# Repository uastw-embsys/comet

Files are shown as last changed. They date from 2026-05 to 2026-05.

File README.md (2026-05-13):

<!-- SPDX-License-Identifier: CC-BY-SA-4.0 -->

# COMET - Cost-efficient Open-Source Multicopter for Embedded-Systems Teaching

<div align="center">
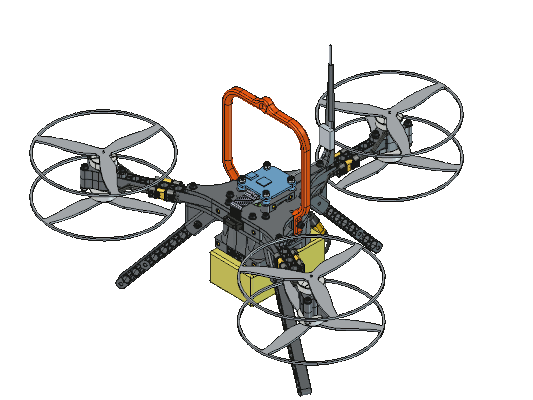
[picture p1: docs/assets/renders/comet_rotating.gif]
    
</div>

<!-- https://github.com/badges/shields -->
<!-- ![GitHub Release](https://img.shields.io/github/v/release/uastw-embsys/comet?display_name=tag)  -->
 

## Description

COMET is an open-source, cost-efficient Y6 hexacopter platform designed for education and research in embedded and cyber-physical systems. It features a fully 3D-printed, modular Y-frame with coaxial brushless DC motors and propellers that provide redundancy in propulsion. COMET also has a standardized motor-controller connector that allows for the easy integration of your preferred flight controller. This repository includes CAD sources, printable STL files, 3MF slicer projects, a bill of materials, a comprehensive build manual, and a ready-to-fly INAV configuration to ensure easy reproducibility.

Key specifications:
- Build it for less than $600 in total
- Frame size: 30cm
- Propellers: 5.1x2.5 (3 blades)
- Motors: 2004 1600KV-1900KV
- Power: 6S LiPo
- Recommended 3D printing materials: PC/CF for the frame and PETG for color coding.
- The recommended electronics are listed in the [bill of materials](/docs/bill_of_materials.ods).

## Table of Contents

- [Documentation](#documentation)
- [Repository Structure](#repository-structure)
- [Safety](#safety)
- [Releases and Versioning](#releases-and-versioning)
- [Licenses](#licenses)
- [Cite This Work](#cite-this-work)
- [OSHWA Certification (planned)](#oshwa-certification-planned)
- [Authors and Acknowledgment](#authors-and-acknowledgment)
- [Disclaimer](#disclaimer)

## Documentation

- Access the project website and documentation through: https://uastw-embsys.github.io/comet
- Latest release: https://github.com/uastw-embsys/comet/releases

Quick links:
  - Bill of Materials: [docs/bill_of_materials.ods](/docs/bill_of_materials.ods)
  - Printing guide: [docs/printing.md](/docs/printing.md)
  - Build manual: [docs/build.md](/docs/build.md)
  - FCU and ESC config: [docs/config.md](/docs/config.md)
  - Safety instructions: [docs/safety.md](/docs/safety.md)

[Back to the top &#8593;](#comet---cost-efficient-open-source-multicopter-for-embedded-systems-teaching)

## Repository Structure

In this repository, "mechanical" refers to printed parts, mechanical components, and assemblies, while "electronics" refers to commercial off-the-shelf (COTS) drone components, wiring, and configurations. According to the OSHWA definition, both are part of the “hardware”, but we separate them for clarity.

### Folders and Files

```
/
├── LICENSES/                            # Contains all licenses that are used
├── docs/
│   ├── assets/
│   │   ├── fonts/                       # Fonts used in the project
│   │   ├── images/                      # Pictures used in all Markdown files
│   │   └── renders/                     # Exported screenshots and animations
│   ├── assembly.md
│   ├── bill_of_materials.ods            # Detailed list of all parts needed
│   ├── build.md                         # Instructions for building COMET hardware
│   ├── config.md                        # Instructions for configuring COMET electronics
│   ├── index.md                         # Documentation landing page
│   ├── printing.md                      # Instructions for printing COMET hardware
│   └── safety.md                        # General drone/COMET safety instructions
├── electronics/
│   ├── esc/                             # Supported ESC configs (e.g., Bluejay)
│   │   └── bluejay/
│   │       └── configs/
│   │           └── <VERSION>/
│   │               ├── <TARGET>/        # YAML file documents all parameter values
│   │               │   ├── esc-configurator-*.png
│   │               │   └── parameters-*.yaml
│   │               └── README.md        # Description of how to configure ESCs
│   ├── fcu/                             # Supported FCU configs (e.g., INAV)
│   │   └── inav/
│   │       └── configs/
│   │           └── <VERSION>/
│   │               ├── <TARGET>/
│   │               │   └── diff-*.txt   # Contains all setting changes
│   │               └── README.md        # Description of how to configure the FCU
│   └── wiring/
│       └── wiring-diagram.svg           # Shows how components are connected and interfaced
├── mechanical/
│   ├── exports/                         # Generated artifacts (STEP and STL, do not edit)
│   ├── prints/                          # Supported slicer configs (e.g., PrusaSlicer)
│   │   ├── prusaslicer/
│   │   │   └── <PRINTER>/               # Printer-specific (e.g., COREONE) project files
│   │   │       └── <MATERIAL>/          # At least one folder named after the material(s) used
│   │   │       │   ├── clearance-gauge-*.3mf
│   │   │       │   ├── color-coding-*.3mf
│   │   │       │   └── frame-*.3mf
│   │   │       └── prusaslicer-bundle-Prusa<PRINTER>.ini
│   │   └── README.md
│   └── source/
│       ├── assemblies/                  # FreeCAD assemblies (A2plus workbench)
│       ├── calibration/
│       │   ├── clearance_gauge.FCStd
│       │   └── README.md
│       ├── macros/
│       │   ├── apply_parameters.py      # Apply part settings to FreeCAD parts
│       │   ├── common_fc.py
│       │   └── export_source.py         # FreeCAD export script
│       ├── part_parameters.yaml         # FreeCAD YAML parameter file
│       ├── parts/                       # FreeCAD part files (one Body per part)
│       └── README.md
└── README.md
```

### Source vs. Exports
The "source" (preferred form for modification) is under `mechanical/source/`. Generated artifacts (STL/STEP and 3MF) are under `mechanical/exports/` and `mechanical/prints/` after the use of `scripts/export_source.py`.

[Back to the top &#8593;](#comet---cost-efficient-open-source-multicopter-for-embedded-systems-teaching)

## Safety

Drones combine fast-spinning parts, high-energy batteries, and radio-controlled systems. Take a few simple precautions to reduce the risk of injury, equipment damage, and legal complications.

Treat setup and testing as seriously as flight:
- Remove propellers during INAV or Bluejay configuration and bench testing.
- Verify the motor spin direction and failsafes before putting propellers on.
- Follow local UAV regulations and only fly in permitted, safe areas within your line of sight.
- Handle LiPo batteries carefully and follow the best practices for charging and storing them.

Detailed **safety instructions** can be found in the [`docs/safety.md`](/docs/safety.md) file.

[Back to the top &#8593;](#comet---cost-efficient-open-source-multicopter-for-embedded-systems-teaching)

## Releases and Versioning

All releases use a semantic versioning scheme: MAJOR.MINOR.PATCH (e.g., v1.0.0).

Each release includes:
  - STEP and STL files for all printed parts
  - 3MF and INI project files for different 3D printers
  - PDF of the bill of materials
  - PDF of the documentation (e.g., build manual)
  - INAV and Bluejay configuration files

[Back to the top &#8593;](#comet---cost-efficient-open-source-multicopter-for-embedded-systems-teaching)

## Licenses

License application by content type:

- Hardware (e.g., CAD sources):  
CERN-OHL-W v2 - see [`LICENSES/LICENSE.CERN-OHL-W-2.0.txt`](/LICENSES/LICENSE.CERN-OHL-W-2.0.txt).
- Documentation (e.g., manuals or photos):  
CC BY-SA 4.0 - see [`LICENSES/LICENSE.CC-BY-SA-4.0.txt`](/LICENSES/LICENSE.CC-BY-SA-4.0.txt).
- Configuration Files (e.g., INAV or Bluejay):  
CC0-1.0 - see [`LICENSES/LICENSE.CC0-1.0.txt`](/LICENSES/LICENSE.CC0-1.0.txt).
- Software (e.g., scripts):  
LGPLv3 - see [`LICENSES/LICENSE.LGPL-3.0.txt`](/LICENSES/LICENSE.LGPL-3.0.txt).
- This project uses the Teko font, designed by Indian Type Foundry (2014), available under the SIL Open Font License, Version 1.1 - see [`docs/assets/fonts/teko/OFL.txt`](/docs/assets/fonts/teko/OFL.txt).

By contributing, you agree that your contributions are provided under the same licenses.

[Back to the top &#8593;](#comet---cost-efficient-open-source-multicopter-for-embedded-systems-teaching)

## Cite This Work

If you use or adapt the device for any academic or industrial purpose, especially if you publish it, please cite this repository and the relevant prior work.

### BibTeX repository
```bibtex
@misc{Comet_v1_0_0,
  author = {Christoph Böhm and Roman Beneder},
  title = {GitHub Repository: COMET - Cost-Efficient Open-Source Multicopter for Embedded Systems Teaching},
  year = {2026},
  howpublished = {\url{https://github.com/uastw-embsys/comet}},
  note = {DOI pending; version 1.0.0}
}
```

### BibTeX companion paper
```bibtex
@article{CometPaper2026,
  author  = {Christoph Böhm and Roman Beneder},
  title   = {COMET: Cost-Efficient Open-Source Multicopter for Embedded Systems Teaching},
  journal = {TechRxiv},
  volume = {2026},
  number = {0227},
  pages = {},
  year = {2026},
  doi = {10.36227/techrxiv.177222563.34103951/v1}
}
```

<!-- Once Zenodo is enabled and a release is archived, replace the “pending” text and add the Zenodo badge -->

[Back to the top &#8593;](#comet---cost-efficient-open-source-multicopter-for-embedded-systems-teaching)

## OSHWA Certification (planned)

- OSHWA UID: **Certification pending**; The planned certification UID (e.g., US000XXX) will be added here once approved. We plan to certify under OSHWA once v1.0.0 is released and the documentation is finished.
- This project complies with the Open Source Hardware Definition: https://www.oshwa.org/definition/
- Certification details and logo usage: https://certification.oshwa.org/

Interim Compliance Summary:

- Editable design files (FreeCAD .FCStd)
- Manufacturing files (STEP/STL)
- 3D print project files (3MF/INI)
- Bill of materials including standards and suppliers
- Build and configuration instructions (multiple manuals)
- Open licenses applied and documented

[Back to the top &#8593;](#comet---cost-efficient-open-source-multicopter-for-embedded-systems-teaching)

## Authors and Acknowledgment

### Authors (Credit roles in parentheses)

- [Christoph Böhm](https://scholar.google.com/citations?user=uV0KBoEAAAAJ) (Project initiator, developer, and maintainer)
- [Roman Beneder](https://embsys.technikum-wien.at/staff/beneder/index.php) (Project co-developer and test pilot)

Corresponding author: **Christoph Böhm** - christoph.boehm@ieee.org

### Contributors

- [Johannes Anderle](https://embsys.technikum-wien.at/staff/anderle/index.php)
- [Samuel Bauer](https://embsys.technikum-wien.at/staff/bauer/index.php)
- [Christian Fibich](https://embsys.technikum-wien.at/staff/fibich/index.php)
- [Ilva Heindl](https://embsys.technikum-wien.at/staff/heindl/index.php)
- [Ana Kokic](https://embsys.technikum-wien.at/staff/kokic/index.php)
- [Patrick Schmitt](https://embsys.technikum-wien.at/staff/schmitt/index.php)

### Acknowledgments

- [Research Group: Embedded Systems](https://embsys.technikum-wien.at/) for funding, workspace, and equipment
- We thank the open‑source communities whose software and content we rely on, including but not limited to:
  - FreeCAD and community workbenches
  - INAV flight software and INAV Configurator
  - Slicers used for supplied profiles (e.g., PrusaSlicer)
  - Icons and fonts used in this project
<!-- - This work was partially supported by <Grant/Company> (Grant no. XXX) -->

[Back to the top &#8593;](#comet---cost-efficient-open-source-multicopter-for-embedded-systems-teaching)

## Disclaimer
**This is experimental hardware. Use it at your own risk and comply with all local laws and regulations.**

[Back to the top &#8593;](#comet---cost-efficient-open-source-multicopter-for-embedded-systems-teaching)

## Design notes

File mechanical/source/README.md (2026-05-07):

<!-- SPDX-License-Identifier: CC-BY-SA-4.0 -->
# Source README

This directory contains the “Source” for the hardware design — the preferred form for making modifications — as required by the CERN Open Hardware License v2 (CERN‑OHL‑W).

What this means
- The FreeCAD `*.FCStd` files here are editable project sources.
- Generated artifacts (STL/STEP/3MF) live under `../exports/` and are not the canonical editing form.
- If you redistribute Products based on this design, you must provide a notice pointing to this Source and license.

## Contents and conventions

- parts/
  - One manufacturable part per `*.FCStd`
  - Each file has a top‑level Body with a stable Label (e.g., `mounting_plate`, `rotor_arm`)
  - Parameters stored in a Spreadsheet object (Label: `params`), referenced by aliases (e.g., `'m3_hole_diameter_clearance`, `'threaded_insert_outer_diameter`)
- assemblies/
  - Assembly files (e.g., Assembly3) linking parts via `App::Link`
  - Local Coordinate Systems (LCS) used for constraints
- params/
  - YAML parameter sets (e.g., `default.yaml`, variant files)

FreeCAD version
- Designed and tested with 1.1.0.44227 +568 (Git) Snap 2266. Other versions may work but are not guaranteed.

## Editing guidelines

- Avoid attaching sketches/features to generated faces (topological naming issue). Use Datum planes/axes and LCS.
- Keep a “master sketch” per part for core layout; parameterize via the `params` Spreadsheet.
- Apply fillets/chamfers late in the feature tree.
- Name key features (e.g., `Sketch_Master`, `Pad_Main`, `Hole_M3_Insert`) for clarity.
- Update revision numbers (R#) in file names and meta when geometry changes.

## Parameters and variants

- Default parameters are stored in each part’s `params` Spreadsheet.
- Variant sets live under `params/variants/`. Load them before recompute/export (see scripts).
- Typical aliases:
  - `m3_hole_diameter_clearance`, `threaded_insert_outer_diameter`, etc.

## Assemblies

- Use stable Labels in parts so assembly links don’t break.
- Constrain via LCS‑to‑LCS where possible.
- Keep sub‑assemblies (e.g., `motor_block`) separate and link into the main assembly.

## Exporting

- Exports are generated headless via `freecad.cmd` using `scripts/export_freecad.py`.
- STL/STEP/3MF are written to `../exports/`.
- Do not hand‑edit exports; modify the `*.FCStd` source and re‑export.

## Licensing

- SPDX for source files: `CERN-OHL-W-2.0`
- Include license and source URL in FreeCAD document metadata:
  - Document → Properties → Meta → `License = CERN-OHL-W-2.0`
  - `Comment = Source: https://github.com/uastw-embsys/comet`
- Full license text: `LICENSES/LICENSE.CERN-OHL-W-2.0.txt`

Third‑party models

- External CAD (e.g., GrabCAD) must be segregated under `third-party/` with clear attribution and original license. These files are not covered by CERN‑OHL‑W unless explicitly stated.
- See `LICENSES/THIRD-PARTY-NOTICES.md` for details.

## Contributing

- Edit `*.FCStd` in `parts/` or `assemblies/` only; keep exports in sync via scripts.
- Add/maintain parameter aliases for new features.
- Run validation scripts (dimension/mesh checks) before submitting PRs.
- Use SPDX headers in text files and keep meta info updated in `*.FCStd`.

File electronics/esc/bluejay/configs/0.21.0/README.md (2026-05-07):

<!-- SPDX-License-Identifier: CC-BY-SA-4.0 -->

# Bluejay 0.21.0 Configurations

This folder contains configuration files for supported electronic speed controller targets tested with COMET using Bluejay. Use the ESC Configurator to flash your electronic speed controller(s) with the official Bluejay 0.21.0 release, then apply the appropriate settings.

- Bluejay 0.21.0 release: https://github.com/bird-sanctuary/bluejay/releases/tag/v0.21.0
- ESC Configurator: https://esc-configurator.com/

Note: These configurations are intended for BLHeli_S electronic speed controllers that are compatible with Bluejay (no support for BLHeli_32).

## Supported targets

- [J-H-50 (4-in-1)](https://www.speedybee.com/speedybee-f405-bls-50a-30x30-4-in-1-esc/): [configs/0.21.0/J-H-50/parameters-bluejay-0.21.0-J-H-50.yaml](/J-H-50/parameters-bluejay-0.21.0-J-H-50.yaml)
- [Q-H-50 (4-in-1)](https://www.rotorama.com/product/skystars-ko50a-bls): [configs/0.21.0/Q-H-50/parameters-bluejay-0.21.0-Q-H-50.yaml](/Q-H-50/parameters-bluejay-0.21.0-Q-H-50.yaml)

If your build uses a different target, create a new subfolder under `0.21.0/` using the Bluejay target name, as shown in the ESC Configurator.

## Prerequisites

- ESC Configurator reachable and up to date
- **Propellers removed** and LiPo connected and powering the ESC(s)
- Stable USB connection through FCU pass-through

## Apply the configuration

Steps to follow:
1) Open https://esc-configurator.com/ in a Chromium-based browser.
2) Connect to the ESC(s) and click "Read Settings" to ensure a stable USB connection and pass-through.
3) Click on "Flash All ESCs" and select the following settings:
   - Firmware: Bluejay
   - ESC (Target): Select the exact target (e.g., Q-H-30). If you are unsure, use Auto-Detect, then confirm against the ESC silkscreen or datasheet.
   - Version: 0.21.0
   - PWM Frequency: Select the value defined by the `pwm_khz` variable in the chosen target parameters file: `parameters-bluejay-0.21.0-<TARGET>.txt`.
4) Wait until all the ESCs have been flashed.
5) Update the values of the parameters in the "Common Parameters" section to match the values specified in the file `parameters-bluejay-0.21.0-<TARGET>.txt.`
6) Click "Write Settings" and, if prompted, power-cycle the ESC.

A note about the motor spin direction: You can adjust the motor direction through the motor ESC wiring, the Bluejay configuration, or the INAV configuration. **The first option is preferred for consistency.**

## Post-flash checks

After applying the new settings:
- Verify motor order and direction. Use the INAV Configurators Output tab to spin individual motors.
- Perform a short throttle range test without the propellers to confirm that there is no desyncing (stuttering or stopping) or excessive heat.

## Troubleshooting

- ESC not detected: Provide external power or follow the bootloader pad procedure for your ESC. Refer to its documentation for more information.
- Desync or rough running: Set the PWM to 24 kHz, increase the demag compensation to "High", and/or increase the motor timing.
- Wrong motor order: Either switch the DShot ESC connector wires or correct the INAV resource/motor mapping. **The first option is preferred for consistency.**

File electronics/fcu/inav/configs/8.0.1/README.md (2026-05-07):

<!-- SPDX-License-Identifier: CC-BY-SA-4.0 -->

# INAV 8.0.1 Configurations

This folder contains CLI diffs ("diff all") for the supported flight controller targets that have been tested with COMET. Flash your flight controller with the official INAV 8.0.1 release, then apply the appropriate diff.

- INAV 8.0.1 release: https://github.com/iNavFlight/inav/releases/tag/8.0.1
- INAV Configurator 8.0.1 release: https://github.com/iNavFlight/inav-configurator/releases/tag/8.0.1

## Supported targets

- [MICOAIR743V2](https://micoair.com/flightcontroller_micoair743v2/): [configs/8.0.1/MICOAIR743V2/diff-inav-8.0.1-MICOAIR743V2.txt](/MICOAIR743V2/diff-inav-8.0.1-MICOAIR743V2.txt)

If your build uses a different target, create a new subfolder under `8.0.1/` with the target name as it appears in the INAV Configurator.

## Prerequisites

- INAV Configurator installed
- Correct USB drivers for your flight controller
- **Propellers removed** and LiPo disconnected for configuration

## Apply the configuration

Steps to follow:
1) Flash INAV 8.0.1 using the official instructions for your specific target (check the board's silkscreen and the INAV target name).
2) Connect using the INAV Configurator and open the CLI tab.
3) Paste the contents of the selected `diff-inav-8.0.1-<TARGET>.txt` into the CLI tab.
4) Press Enter and wait for the commands to take effect.
5) Type "save" to reboot.

## Post-flash calibrations and checks

After applying the new settings:
- Calibrate the accelerometer and magnetometer. Then, verify the barometer's function.
- Verify motor order and direction. Use the INAV Configurators Output tab to spin individual motors.
- Bind the RC remote and receiver according to the manual and verify or reconfigure the receiver protocol and channel mapping.
- Set the failsafe to "drop" or according to your regulations.

## Troubleshooting

- CLI rejects lines: Ensure that the flight controller target matches and that you are using INAV 8.0.1.
- Resources conflict: Compare your wiring to the [wiring diagram](../../../../wiring/wiring-diagram.svg).
- Sensor (gyro) init fails: Check the mounting orientation and vibration isolation.

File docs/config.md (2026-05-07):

<!-- SPDX-License-Identifier: CC-BY-SA-4.0 -->

# FCU and ESC Configuration - NOTES

### 5) Flash and configure INAV

- Flash official INAV 8.0.1 for your target (linked in docs/firmware.md).
- INAV Configurator → CLI → paste electronics/inav/configs/8.0.1/<target>/diff.txt → save.
- Calibrate accelerometer, magnetometer, radio; verify failsafe and motor order/direction.

- See [INAV Configuration](#inav-configuration) for details.
- Install INAV 8.0.1 for your <target> board 
- In INAV CLI: paste the diff from electronics/inav/configs/8.0.1/<target>/diff.txt.
- Safety: [`docs/build-manual/safety.md`](/docs/build-manual/safety.md)
- Flash the official INAV 8.0.1 for your flight controller target (linked in docs/firmware/).
- Apply the configuration diff at: electronics/inav/configs/8.0.1/<target>/diff.txt.
- Calibrate (accel, mag, radio) and verify failsafe before flight.

- Target firmware: INAV 8.0.1 for target <YOUR_FC_TARGET> (flight controller target)
  - We do not distribute INAV. Official releases: https://github.com/iNavFlight/inav/releases
- Apply configuration: electronics/inav/configs/8.0.1/<target>/diff.txt
- How: INAV Configurator → CLI → paste diff → save → reboot
- Instructions: docs/firmware/index.md
- Tuning and presets
  - Initial PID/rates and filters are noted in electronics/inav/configs/…/README.md

4) Flash iNav 8.0.1 to your FC target and apply config diff.
5) Validate motor order/direction; check OSD and failsafe.

Checklist
- Arming works only when safe (switch + checks).
- Failsafe behavior set (e.g., disarm or RTH if GPS present).
- OSD elements visible; voltage alarm configured.

## Firmware (iNav) setup

We do not ship firmware binaries. We link to iNav and provide a reproducible configuration.

- Version: iNav 8.0.1
- Target: [e.g., MATEKF405] — see flight/inav/target.md
- Links: flight/inav/links.md (official release and Configurator)
- Apply config:
  1) Flash iNav 8.0.1, then Reset to defaults once.
  2) Configurator → CLI → paste flight/inav/config/inav-8.0.1/TARGET_<YOURTARGET>/diff_all.txt
  3) Enter `save`. Calibrate sensors, verify receiver and motor order.
- Reference:
  - dump_all.txt for verification
  - osd_layout.json and rates_pid_profiles.json (if provided)
- ESC:
  - See flight/esc/ notes for protocol (e.g., DSHOT600), bidirectional RPM, and motor directions.

- Target firmware: INAV 8.0.1 for target <YOUR_FC_TARGET> (flight controller target)
  - We do not distribute INAV. Official releases: https://github.com/iNavFlight/inav/releases
- Apply configuration: electronics/inav/configs/8.0.1/<target>/diff.txt
- How: INAV Configurator → CLI → paste diff → save → reboot
- Instructions: docs/firmware/index.md
- Tuning and presets
  - Initial PID/rates and filters are noted in electronics/inav/configs/…/README.md

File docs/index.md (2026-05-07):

<!-- SPDX-License-Identifier: CC-BY-SA-4.0 -->

# Documentation Index

Welcome to the COMET documentation! This documentation will guide you through the processes of preparing, printing, assembling, setting up the electronics, configuring, and safely operating the drone.

<div align="center">
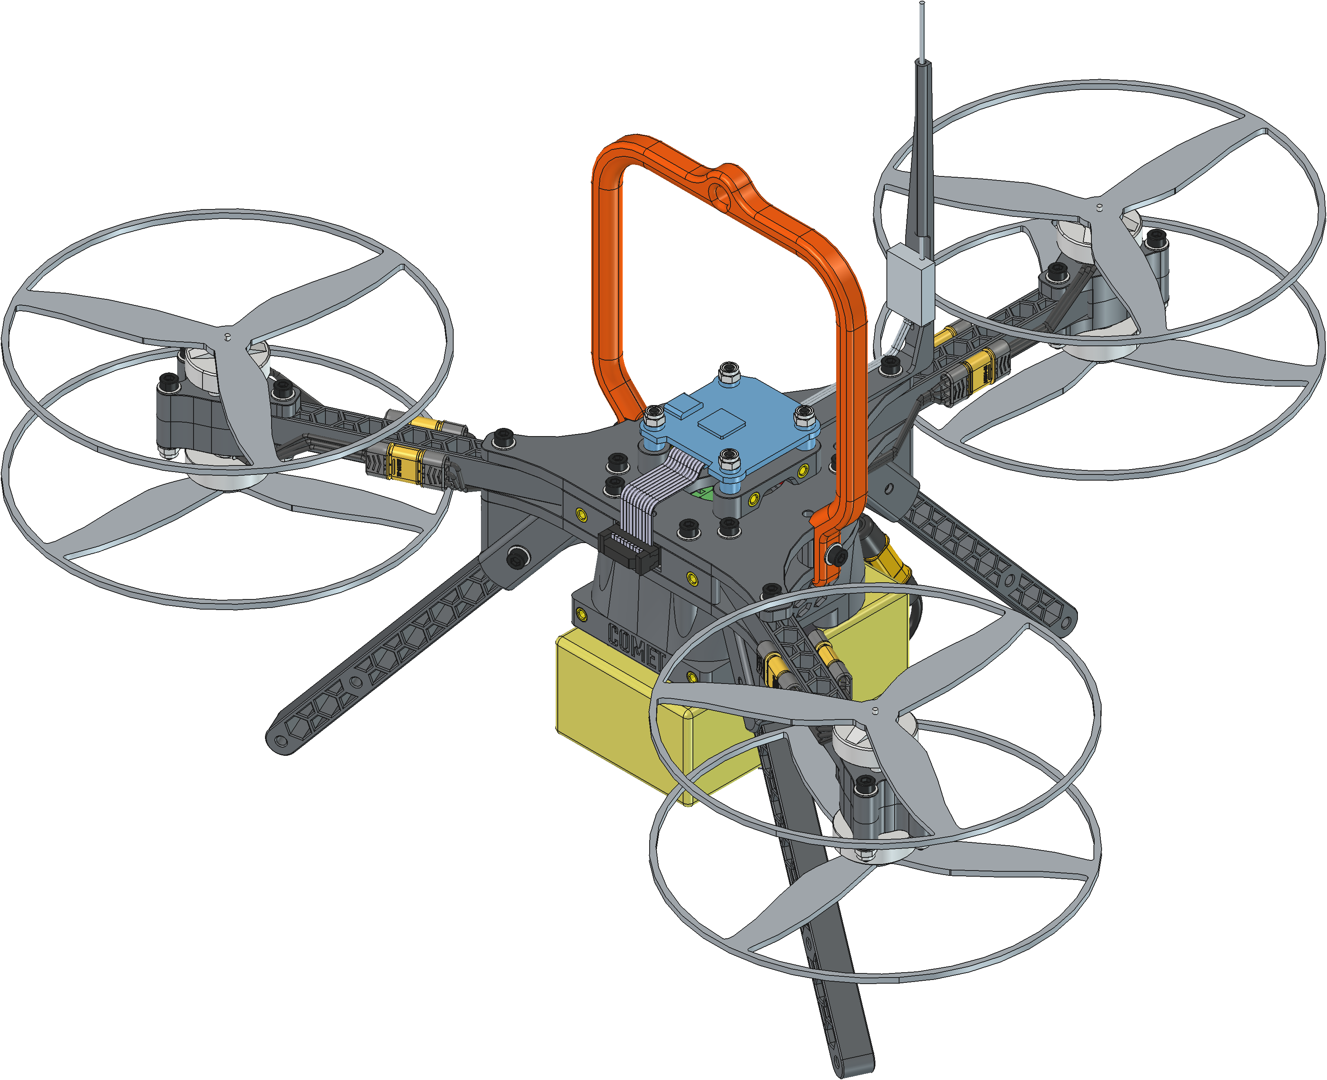
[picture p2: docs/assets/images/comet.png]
    
</div>

Quick Links:
  - Bill of Materials: [docs/bill_of_materials.ods](/docs/bill_of_materials.ods)
  - Printing guide: [docs/printing.md](/docs/printing.md)
  - Build manual: [docs/build.md](/docs/build.md)
  - FCU and ESC configuration: [docs/config.md](/docs/config.md)
  - Safety instructions: [docs/safety.md](/docs/safety.md)

## Software

The following is a list of the software used to create, 3D print, and operate COMET:
- [FreeCAD 1.1.0](https://github.com/FreeCAD/FreeCAD/releases/tag/1.1.0) and [A2plus Workbench 0.4.68](https://github.com/kbwbe/A2plus)
- [Python 3.12.3](https://www.python.org/downloads/release/python-3123/)
- [PrusaSlicer 2.9.4](https://github.com/prusa3d/PrusaSlicer/releases/tag/version_2.9.4)
- [INAV Configurator 8.0.1](https://github.com/iNavFlight/inav-configurator/releases/tag/8.0.1)

[Back to the top &#8593;](#documentation-index)

## Tools

The following is a list of the tools needed to build COMET:
- length ruler (from the 3D-printed frame parts)
- side cutter
- nose plier
- soldering iron, solder, and flux
- 1.5mm allen key
- 2.5mm allen key
- 5.5mm open-jaw wrench
- tweezers
- zip ties (different sizes)
- shrinking tube (different sizes)
- (optional) cable striper
- (optional) threaded inserts melting [aid set](https://www.3djake.com/ruthex/soldering-tips-melting-aid-set?similar_products_d_a=30899)

[Back to the top &#8593;](#documentation-index)

## Quick Start

The following steps will guide you through the process of building your very own COMET drone.

### 1) Get the files

- Download one of the [release ZIPs](https://github.com/uastw-embsys/comet/releases)
- Or clone the repository:
```bash
git clone https://github.com/uastw-embsys/comet.git
```

### 2) Order the non-printable parts

- Refer to the "bill of materials" sheet in the [docs/bill_of_materials.ods](./bill_of_materials.ods) document. It contains a detailed list of parts grouped by subassemblies stemming from the [build manual](./build.md).
- The "order list" sheet is recommended for the initial order of materials because it includes the initial purchase of filament spools that can be used for multiple drones. Do not order the filament spools if they are already available.

### 3) 3D print the frame

- Ensure that the 3D printer is calibrated for the elephant foot and for over- and under-extrusion.
- Use 3MF projects in `mechanical/prints/` that match your slicer and 3D printer.
  1) Print the clearance gauge using the intended filament.
  2) Verify that the printed parts match the dimensions of the critical hole diameters and part clearances.
  3) Update the parameters of the parts.
  4) Print the frame and miscellaneous parts. The frame needs ~200 g of filament.
- Install heat-set inserts where specified.
- For more detailed instructions, refer to the printing guide in [docs/printing.md](/docs/printing.md).

### 4) Assemble COMET

- Begin by assembling the individual COMET subassemblies.
- Assemble all subassemblies and finish the wiring.
- Perform final checks to ensure that the build is correct.
- Enjoy your self-built drone!
- For more detailed instructions, refer to the build manual in [docs/build.md](/docs/build.md).

### 5) Flash and configure the FCU and ESCs

- Flash the official INAV 8.0.1 for your target onto the flight controller board.
- Apply the diff-*.txt file to the COMET settings in INAV, then save and reboot.
- Calibrate the accelerometer, magnetometer, and  radio.
- Use the ESC Configurator to flash the target ESC with Bluejay firmware.
- Apply the parameters and perform a power cycle for the ESC to take effect.
- Verify the failsafe and the motor order and direction.
- For more detailed instructions, refer to the FCU and ESC configuration in [docs/config.md](/docs/config.md).

### 6) First test flight!

- Perform all checks according to the safety instructions found in the [`docs/safety.md`](/docs/safety.md) file.
- Let us know about your successful maiden flight!

[Back to the top &#8593;](#documentation-index)

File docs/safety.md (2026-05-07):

<!-- SPDX-License-Identifier: CC-BY-SA-4.0 -->

# Safety instructions - DRAFT

Read and follow this guidance before building and flying. Drones can cause injury or property damage if misused.

## 1. Legal and regulatory

- Know and comply with local laws:
  - Registration, identification, and remote ID (where applicable).
  - Maximum altitude, no‑fly zones, and VLOS (visual line of sight) rules.
  - Insurance and permissions for commercial use.
- Do not fly near people, traffic, airports, or sensitive areas.
- Respect privacy.

## 2. Workshop and build safety

- Eye protection when soldering, cutting, or pressing inserts.
- Ventilation when soldering and using adhesives.
- Keep flammable materials away from the bench.
- Unplug battery before working on electronics.

## 3. Electrical and battery safety

- Use quality batteries appropriate for your setup.
- Inspect cells for damage; do not use bloated or punctured packs.
- Charging:
  - Use a balance charger on a non‑flammable surface.
  - Never leave charging batteries unattended.
- During flight:
  - Monitor battery voltage; land before deep discharge.
  - Allow batteries to cool before recharging.

## 4. Propellers and motors

- Always remove props when configuring firmware and testing motors on the bench.
- Keep fingers, clothing, and tools away from spinning props.
- Inspect props for chips/cracks; replace if damaged.
- Install props with correct orientation (CW/CCW) and tighten properly.

## 5. Pre‑flight checklist

- Mechanical
  - All screws tight; snug plus quarter‑turn; avoid over‑tightening
  - No cracks or delamination in printed parts.
  - Wires secured; no rubbing against props.
- Electronics
  - Correct FC orientation; sensors calibrated.
  - Receiver bound; channel map correct.
  - Motor order/direction verified without props.
- Firmware
  - iNav version and target match documentation.
  - Failsafe configured according to regulations.
  - Battery voltage and alarms set; arming checks enabled.
- Environment
  - Open area; wind within safe limits.
  - People and pets at a safe distance.

## 6. Initial flight and testing

- Perform first hover at low altitude; be ready to disarm.
- Increase altitude gradually; check stability and response.
- If oscillations or abnormal behavior occur, land and troubleshoot.

## 7. Post‑flight and maintenance

- Inspect frame and mounts after hard landings.
- Check motor temperatures; listen for bearing noise.
- Retighten fasteners; recheck electrical connections.
- Log issues and update tuning if needed.

## 8. Liability and disclaimer

- This is experimental hardware. You are responsible for safe operation and compliance with local laws.
- The authors and contributors are not liable for damages resulting from use or misuse.
- Follow manufacturer guidelines for all third‑party components.

**Stay safe, fly responsibly, and enjoy building and tuning COMET.**

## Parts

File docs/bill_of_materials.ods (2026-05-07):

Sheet: bill of materials
1 | COMET drone(s)
3 | Motor Blocks
 | Item No. | Manufacturer | Part Number | Part Name | Description | Source | Quantity | Unit of Measure | max. Weight/Unit | Weight | Price incl. VAT/Unit | Price | 2nd Source
 | MB-01 | 3D print | motor_mount.3mf | motor mount | PC CF (motor heat!) | CAD | 6 | piece(s) | 4.4 g | 26.4 g | € 0.36 | € 2.18
 | MB-02 | GepRC | GP104587 | BLDC motor | 2004 1750KV, T-mount 1.5mm | https://www.modell-hubschrauber.at/RC-FPV-Racer-Kameras-Videobrillen-und-co/FPV-Racer-Motoren-und-Motoren-Zubehoer/FPV-Racer-Motoren/GepRC-Motor-2004-mit-1750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 | 6 | piece(s) | 16.8 g | 100.8 g | € 21.99 | € 131.94
 | MB-03 |  |  | M2 x 5mm button head screw | could be M2 x 6mm or M2 x 7mm too, come with BLDC motors (MB-02) |  | 24 | piece(s) | 0.25 g | 6 g
 | MB-04 | miscellaneous | 14425 | M2 washer | DIN 125, pack of 10 pieces | https://www.modell-hubschrauber.at/Schrauben-Unterlegscheiben-Muttern-Bauzubehoer/Unterlegscheiben/Unterlegscheiben-galvanisiert-M2-10Stueck::22310.html | 24 | piece(s) | 0.04 g | 1 g | € 0.15 | € 3.58 | https://at.rs-online.com/web/p/unterlegscheiben/0527347
 | MB-05 | miscellaneous | 14194 | MR30 male connector | Male MR30 connector, for BLDC side | https://www.modell-hubschrauber.at/Adapter-Kabel-Stecker/Buchsen-und-Stecker/MR30-3-poliger-Motor/Regler-Stecker::22526.html | 6 | piece(s) | 1.4 g | 8.4 g | € 0.99 | € 5.94 | https://at.rs-online.com/web/p/steckergehause-und-stecker/3922262
 | MB-06 | miscellaneous | 20247 | M3 x 25mm socket head screw | DIN 912, full thread, pack of 10 pieces | https://www.modell-hubschrauber.at/Schrauben-Unterlegscheiben-Muttern-Bauzubehoer/Inbusschrauben/Inbusschrauben-M3/Inbusschrauben-M3x25-10Stueck::19526.html | 9 | piece(s) | 1.7 g | 15.3 g | € 0.30 | € 2.69 | https://at.rs-online.com/web/p/innensechskantschrauben/0293325
 | MB-07 | miscellaneous | 14423 | M3 washer | DIN 125, pack of 10 pieces | https://www.modell-hubschrauber.at/Schrauben-Unterlegscheiben-Muttern-Bauzubehoer/Unterlegscheiben/Unterlegscheiben-galvanisiert-M3-10Stueck::22312.html | 18 | piece(s) | 0.12 g | 2.2 g | € 0.15 | € 2.68 | https://at.rs-online.com/web/p/unterlegscheiben/0527369
 | MB-08 | miscellaneous | 20222 | M3 self-locking nut | DIN 985, pack of 10 pieces | https://www.modell-hubschrauber.at/Schrauben-Unterlegscheiben-Muttern-Bauzubehoer/Muttern-Stoppmuttern/Stoppmuttern-M3-10Stueck::19548.html | 9 | piece(s) | 0.52 g | 4.7 g | € 0.30 | € 2.69 | https://at.rs-online.com/web/p/sechskantmuttern/0767804
 | MB-09 | Gemfan | GEM-SL5125 | propeller | Grey, 3 blade, 5.1 inch, 2.5 inch pitch, T-mount 1.5mm, matched to motor | https://www.rotorama.de/product/gemfan-sl-5125-3-t | 6 | piece(s) | 3 g | 18 g | € 0.75 | € 4.49
 | MB-10 | miscellaneous | n.d. | M2 x 8mm socket head screw | Propeller screws, DIN 912, full thread, pack of 10 pieces | https://www.rotorama.de/product/sroub-s-valcovou-hlavou-m2-10ks | 12 | piece(s) | 0.25 g | 3 g | € 0.12 | € 1.43
 |  |  |  |  |  |  |  |  |  | 186 g |  | € 158.00
1 | ESC Stack (up to 8 BLDC motors)
 | Item No. | Manufacturer | Part Number | Part Name | Description | Source | Quantity | Unit of Measure | max. Weight/Unit | Weight | Price incl. VAT/Unit | Price
 | ES-01 | 3D print | capacitor_holder.3mf | capacitor holder | PC CF (for rigidity) | CAD | 1 | piece(s) | 1.6 g | 1.6 g | € 0.13 | € 0.13
 | ES-02 | miscellaneous | e.g., Skystars KO50A BLS | ESC | 30x30mm hole spacing, min. 50A 4-in-1 ESC | https://www.rotorama.de/product/skystars-ko50a-bls | 2 | piece(s) | 14.5 g | 29 g | € 44.39 | € 88.78 | https://www.rotorama.de/product/speedy-bee-60a-bls
 | ES-03 |  |  | capacitor | take one form the ESCs (ES-02) |  | 1 | piece(s) | 2.9 g | 2.9 g
 | ES-04 |  |  | XT60 cable | take one form the ESCs (ES-02) |  | 1 | piece(s) | 15.2 g | 15.2 g
 | ES-05 |  |  | ESC connector cable | take two form the ESCs (ES-02), modified |  | 2 | piece(s) | 0.6 g | 1.2 g
 | ES-06 | miscellaneous | 14193 | MR30 female connector | Female MR30 connector, for ESC side | https://www.modell-hubschrauber.at/Adapter-Kabel-Stecker/Buchsen-und-Stecker/MR30-3-poliger-Motor/Regler-Buchse::22527.html | 6 | piece(s) | 1.1 g | 6.6 g | € 0.99 | € 5.94 | https://at.rs-online.com/web/p/crimpkontakte/1613367
 | ES-07 | miscellaneous | 20992 | Silicone cable | 1mm diameter silicone cable, for ESC-motor connection | https://www.modell-hubschrauber.at/Adapter-Kabel-Stecker/Silikonkabel/Silikonkabel-kupfer-1-00mm-schwarz-1Meter::12265.html | 2.25 | meter(s) | 12 g | 27 g | € 1.69 | € 3.80
 | ES-08 | miscellaneous | 20222 | M3 self-locking nut | DIN 985, pack of 10 pieces | https://www.modell-hubschrauber.at/Schrauben-Unterlegscheiben-Muttern-Bauzubehoer/Muttern-Stoppmuttern/Stoppmuttern-M3-10Stueck::19548.html | 4 | piece(s) | 0.52 g | 2.1 g | € 0.30 | € 1.20 | https://at.rs-online.com/web/p/sechskantmuttern/0767804
 | ES-09 | 3M | AWG 28-10G 3M | ribbon cable | Pin 1 red indicator, RM 1.27mm | https://www.reichelt.at/at/de/shop/produkt/flachbandkabel_awg28_10-pol_grau_3m-ring-47637 | 0.06 | meter(s) | 60 g | 3.6 g | € 1.21 | € 0.07 | https://at.rs-online.com/web/p/flachbandkabel/2899846
 | ES-10 | ECON CONNECT | 453345 | male box header | 2.54mm 10pin, IDC, 1.27mm cable strip | https://www.pollin.at/p/econ-connect-wannenstecker-din-41651-10-polig-schneidklemm-rm-2-54-mm-453345 | 1 | piece(s) | 2.7 g | 2.7 g | € 0.59 | € 0.59 | https://at.rs-online.com/web/p/idc-steckverbinder/8236632
 |  |  |  |  |  |  |  |  |  | 92 g |  | € 101.00
3 | Landing Gears
 | Item No. | Manufacturer | Part Number | Part Name | Description | Source | Quantity | Unit of Measure | max. Weight/Unit | Weight | Price incl. VAT/Unit | Price
 | LG-01 | 3D print | landing_gear_mount.3mf | landing gear mount | PC CF (for rigidity) | CAD | 3 | piece(s) | 7.4 g | 22.2 g | € 0.61 | € 1.83
 | LG-02 | 3D print | rotor_arm.3mf | rotor arm | PC CF (for rigidity) | CAD | 3 | piece(s) | 10.9 g | 32.7 g | € 0.90 | € 2.70
 | LG-03 | ruthex | GE-M3x57-001 | M3 thread insert | Pack of 100 pieces, molded into landing gear mount | https://www.3djake.com/ruthex/threaded-insert-m3-100-pieces | 9 | piece(s) | 0.32 g | 2.9 g | € 0.09 | € 0.81
 | LG-04 | miscellaneous | 14423 | M3 washer | DIN 125, pack of 10 pieces | https://www.modell-hubschrauber.at/Schrauben-Unterlegscheiben-Muttern-Bauzubehoer/Unterlegscheiben/Unterlegscheiben-galvanisiert-M3-10Stueck::22312.html | 3 | piece(s) | 0.12 g | .4 g | € 0.15 | € 0.45 | https://at.rs-online.com/web/p/unterlegscheiben/0527369
 | LG-05 | miscellaneous | 20254 | M3 x 10mm socket head screw | DIN 912, pack of 10 pieces | https://www.modell-hubschrauber.at/Schrauben-Unterlegscheiben-Muttern-Bauzubehoer/Inbusschrauben/Inbusschrauben-M3/Inbusschrauben-M3x10-10Stueck::19519.html | 3 | piece(s) | 0.9 g | 2.7 g | € 0.30 | € 0.90 | https://at.rs-online.com/web/p/innensechskantschrauben/7976266
 |  |  |  |  |  |  |  |  |  | 61 g |  | € 7.00
1 | Battery Holder
 | Item No. | Manufacturer | Part Number | Part Name | Description | Source | Quantity | Unit of Measure | max. Weight/Unit | Weight | Price incl. VAT/Unit | Price
 | BH-01 | 3D print | battery_holder.3mf | battery holder | PC CF (for rigidity), optional PETG color-coding ring | CAD | 1 | piece(s) | 30.6 g | 30.6 g | € 2.52 | € 2.52
 | BH-02 | ruthex | GE-M3x57-001 | M3 thread insert | Pack of 100 pieces, molded into landing gear mount | https://www.3djake.com/ruthex/threaded-insert-m3-100-pieces | 2 | piece(s) | 0.32 g | .6 g | € 0.09 | € 0.18
 | BH-03 | miscellaneous | 20247 | M3 x 25mm socket head screw | DIN 912, full thread, pack of 10 pieces | https://www.modell-hubschrauber.at/Schrauben-Unterlegscheiben-Muttern-Bauzubehoer/Inbusschrauben/Inbusschrauben-M3/Inbusschrauben-M3x25-10Stueck::19526.html | 4 | piece(s) | 1.7 g | 6.8 g | € 0.30 | € 1.20 | https://at.rs-online.com/web/p/innensechskantschrauben/0293325
 | BH-04 | miscellaneous | 14423 | M3 washer | DIN 125, pack of 10 pieces | https://www.modell-hubschrauber.at/Schrauben-Unterlegscheiben-Muttern-Bauzubehoer/Unterlegscheiben/Unterlegscheiben-galvanisiert-M3-10Stueck::22312.html | 4 | piece(s) | 0.12 g | .5 g | € 0.15 | € 0.60 | https://at.rs-online.com/web/p/unterlegscheiben/0527369
 | BH-05 | miscellaneous | n.d. | silicone pad | size 50mm x 35mm, stick to the bottom face of the battery holder (BH-01) | https://www.rotorama.de/product/tlusta-silikonova-podlozka-pod-baterii-10ks | 1 | piece(s) | 3 g | 3 g | € 0.40 | € 0.40
 | BH-06 | Rotorama | n.d. | battery strap | strap 20mm wide and 250mm long | https://www.rotorama.de/product/rotorama-battery-strap-pogumovany-kevlar-20x250 | 1 | piece(s) | 7.6 g | 7.6 g | € 1.99 | € 1.99
 |  |  |  |  |  |  |  |  |  | 50 g |  | € 7.00
1 | RC Receiver
 | Item No. | Manufacturer | Part Number | Part Name | Description | Source | Quantity | Unit of Measure | max. Weight/Unit | Weight | Price incl. VAT/Unit | Price
 | RC-01 | 3D print | rc_receiver_mount_FS_A8S.3mf | RC receiver mount FS A8S | PC CF (for rigidity) | CAD | 1 | piece(s) | 3.2 g | 3.2 g | € 0.26 | € 0.26
 | RC-02 | FlySky | FS-A8S | RC receiver | 2.4GHz, 8CH, I-Bus/S-Bus | https://www.proshop.at/Ferngesteuert/FlySky-Receiver-FS-A8S/3248332 | 1 | piece(s) | 5 g | 5 g | € 14.90 | € 14.90 | https://clover.coex.tech/en/rc_flysky_a8s.html
 | RC-03 |  |  | RC receiver connector cable | modified JST SH1.0 4-pin cable, sourced from FC-02 |  | 1 | piece(s) | 1 g | 1 g |  |  | https://clover.coex.tech/en/rc_flysky_a8s.html
 |  |  |  |  |  |  |  |  |  | 10 g |  | € 16.00
1 | Y-Frame
 | Item No. | Manufacturer | Part Number | Part Name | Description | Source | Quantity | Unit of Measure | max. Weight/Unit | Weight | Price incl. VAT/Unit | Price
 | YF-01 | 3D print | mounting_plate.3mf | mounting plate | PC CF (for rigidity) | CAD | 2 | piece(s) | 27.3 g | 54.6 g | € 2.25 | € 4.50
 | YF-02 | 3D print | rotor_arm.3mf | rotor arm | PC CF (for rigidity) | CAD | 3 | piece(s) | 10.9 g | 32.7 g | € 0.90 | € 2.70
 | YF-03 | 3D print | xt30_male_mount.3mf | XT30 connector mount | PC CF (for rigidity) | CAD | 2 | piece(s) | 4.2 g | 8.4 g | € 0.35 | € 0.69
 | YF-04 | 3D print | esc_connector_mount.3mf | ESC connector mount | PC CF (for rigidity) | CAD | 1 | piece(s) | 3.6 g | 3.6 g | € 0.30 | € 0.30
 | YF-05 | 3D print | quick_release_base.3mf | quick release base | PC CF (for rigidity) | CAD | 2 | piece(s) | 2.1 g | 4.2 g | € 0.17 | € 0.35
 | YF-06 | ruthex | GE-M3x57-001 | M3 thread insert | Pack of 100 pieces, molded into XT30 connector mount | https://www.3djake.com/ruthex/threaded-insert-m3-100-pieces | 24 | piece(s) | 0.32 g | 7.7 g | € 0.09 | € 2.16
 | YF-07 | miscellaneous | n.d. | XT30 connector | male connector with cable | https://www.rotorama.de/product/readytosky-xt30-s-kabelem-male | 2 | piece(s) | 7 g | 14 g | € 1.99 | € 3.98
 | YF-08 | miscellaneous | 14423 | M3 washer | DIN 125, pack of 10 pieces | https://www.modell-hubschrauber.at/Schrauben-Unterlegscheiben-Muttern-Bauzubehoer/Unterlegscheiben/Unterlegscheiben-galvanisiert-M3-10Stueck::22312.html | 16 | piece(s) | 0.12 g | 1.9 g | € 0.15 | € 2.38 | https://at.rs-online.com/web/p/unterlegscheiben/0527369
 | YF-09 | miscellaneous | 20254 | M3 x 10mm socket head screw | DIN 912, pack of 10 pieces | https://www.modell-hubschrauber.at/Schrauben-Unterlegscheiben-Muttern-Bauzubehoer/Inbusschrauben/Inbusschrauben-M3/Inbusschrauben-M3x10-10Stueck::19519.html | 6 | piece(s) | 0.9 g | 5.4 g | € 0.30 | € 1.79 | https://at.rs-online.com/web/p/innensechskantschrauben/7976266
 | YF-10 | miscellaneous | 20247 | M3 x 25mm socket head screw | DIN 912, full thread, pack of 10 pieces | https://www.modell-hubschrauber.at/Schrauben-Unterlegscheiben-Muttern-Bauzubehoer/Inbusschrauben/Inbusschrauben-M3/Inbusschrauben-M3x25-10Stueck::19526.html | 10 | piece(s) | 1.7 g | 17 g | € 0.30 | € 2.99 | https://at.rs-online.com/web/p/innensechskantschrauben/0293325
 | YF-11 | miscellaneous | 20246 | M3 x 30mm socket head screw | DIN 912, pack of 10 pieces, could be sourced from ES-02 | https://www.modell-hubschrauber.at/Schrauben-Unterlegscheiben-Muttern-Bauzubehoer/Inbusschrauben/Inbusschrauben-M3/Inbusschrauben-M3x30-10Stueck::19527.html | 4 | piece(s) | 2 g | 8 g | € 0.30 | € 1.20 | https://at.rs-online.com/web/p/innensechskantschrauben/0293331
 |  |  |  |  |  |  |  |  |  | 158 g |  | € 24.00
1 | FCU Stack
 | Item No. | Manufacturer | Part Number | Part Name | Description | Source | Quantity | Unit of Measure | max. Weight/Unit | Weight | Price incl. VAT/Unit | Price
 | FC-01 | MicoAir | MicoAir743v2 | FCU | 30x30mm hole spacing, min. 6 ESC connectors needed | https://www.rotorama.de/product/micoair-h743-v2 | 1 | piece(s) | 9.5 g | 9.5 g | € 52.69 | € 52.69
 | FC-02 | 3M | AWG 28-10G 3M | ribbon cable | Pin 1 red indicator, RM 1.27mm | https://www.reichelt.at/at/de/shop/produkt/flachbandkabel_awg28_10-pol_grau_3m-ring-47637 | 0.06 | meter(s) | 60 g | 3.6 g | € 1.21 | € 0.07 | https://at.rs-online.com/web/p/flachbandkabel/2899846
 | FC-03 | ECON CONNECT | 453341 | female box header | 2.54mm 10pin, IDC, with strain relief | https://www.pollin.at/p/econ-connect-pfostenverbinder-din-41651-10-polig-grau-rm-2-54-mm-453341 | 1 | piece(s) | 1.4 g | 1.4 g | € 0.17 | € 0.17 | https://at.rs-online.com/web/p/idc-steckverbinder/7718373?gb=s
 | FC-04 | miscellaneous | 20222 | M3 self-locking nut | DIN 985, pack of 10 pieces | https://www.modell-hubschrauber.at/Schrauben-Unterlegscheiben-Muttern-Bauzubehoer/Muttern-Stoppmuttern/Stoppmuttern-M3-10Stueck::19548.html | 4 | piece(s) | 0.52 g | 2.1 g | € 0.30 | € 1.20 | https://at.rs-online.com/web/p/sechskantmuttern/0767804
 |  |  |  |  |  |  |  |  |  | 17 g |  | € 55.00
 |  |  |  |  |  |  |  |  | frame estimate | 574 g |  | € 368.00
1 | Additional equipment
 | Item No. | Manufacturer | Part Number | Part Name | Description | Source | Quantity | Unit of Measure | max. Weight/Unit | Weight | Price incl. VAT/Unit | Price
 | EQ-01 | GNB | GNB18506S140A | LiPo Battery | 6S, 22.2V, 1850mAh, 140C, XT60 | https://www.rotorama.de/product/gnb-1850mah-6s-140c | 1 | piece(s) | 302 g | 302 g | € 45.39 | € 45.39
 | EQ-02 | FlySky | FS-i6x | RC remote | 2.4GHz | https://www.d-m-t.at/fernsteuerungen/set-flysky-i6x-mit-empfaenger-fs-ia6b-6-kanal-2-4-ghz-detail | 1 | piece(s) | 0 g | g | € 79.90 | € 79.90
 | CC-01 | 3D print | handle.3mf | handle | PETG colored (to distinguish multiple drones) | CAD | 1 | piece(s) | 22.7 g | 22.7 g | € 0.75 | € 0.75
 | CC-02 | 3D print | remote_label.3mf | remote_label | PETG colored (to distinguish multiple drones) | CAD | 1 | piece(s) | 0 g | g | € 0.18 | € 0.18
 | Last price update: 17.07.2025 |  |  |  |  |  |  |  | max. total | 899 g |  | € 494.22
 | 3D print material
 | Item No. | Manufacturer | Part Number | Part Name | Description | Source | Quantity | Unit of Measure | max. Weight/Unit | Weight | Price incl. VAT/Unit | Price | Price / gram
 | 3P-01 | Prusa | n.d. | PC CF spool | Prusament PC Blend Carbon Fiber Black 800g | https://www.prusa3d.com/de/produkt/prusament-pc-blend-carbon-fiber-black-800g-6/ | 1 | piece(s) | 800 g | 800 g | € 65.99 | € 65.99 | € 0.08
 | 3P-01 | Prusa | n.d. | PETG spool | Prusament PETG Prusa 1kg, colored | https://www.prusa3d.com/product/prusament-petg-prusa-orange-1kg/ | 1 | piece(s) | 1000 g | 1000 g | € 32.99 | € 32.99 | € 0.03

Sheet: order list
 |  | Data
Source (alternative in column N in “bill of materials”) | Part Name | Quantity | Price
https://www.3djake.com/ruthex/threaded-insert-m3-100-pieces | M3 thread insert | 35 | € 3.15
https://www.d-m-t.at/fernsteuerungen/set-flysky-i6x-mit-empfaenger-fs-ia6b-6-kanal-2-4-ghz-detail | RC remote | 1 | € 79.90
https://www.modell-hubschrauber.at/Adapter-Kabel-Stecker/Buchsen-und-Stecker/MR30-3-poliger-Motor/Regler-Buchse::22527.html | MR30 female connector | 6 | € 5.94
https://www.modell-hubschrauber.at/Adapter-Kabel-Stecker/Buchsen-und-Stecker/MR30-3-poliger-Motor/Regler-Stecker::22526.html | MR30 male connector | 6 | € 5.94
https://www.modell-hubschrauber.at/Adapter-Kabel-Stecker/Silikonkabel/Silikonkabel-kupfer-1-00mm-schwarz-1Meter::12265.html | Silicone cable | 2 | € 3.80
https://www.modell-hubschrauber.at/RC-FPV-Racer-Kameras-Videobrillen-und-co/FPV-Racer-Motoren-und-Motoren-Zubehoer/FPV-Racer-Motoren/GepRC-Motor-2004-mit-1750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 | BLDC motor | 6 | € 131.94
https://www.modell-hubschrauber.at/Schrauben-Unterlegscheiben-Muttern-Bauzubehoer/Inbusschrauben/Inbusschrauben-M3/Inbusschrauben-M3x10-10Stueck::19519.html | M3 x 10mm socket head screw | 9 | € 2.69
https://www.modell-hubschrauber.at/Schrauben-Unterlegscheiben-Muttern-Bauzubehoer/Inbusschrauben/Inbusschrauben-M3/Inbusschrauben-M3x25-10Stueck::19526.html | M3 x 25mm socket head screw | 23 | € 6.88
https://www.modell-hubschrauber.at/Schrauben-Unterlegscheiben-Muttern-Bauzubehoer/Inbusschrauben/Inbusschrauben-M3/Inbusschrauben-M3x30-10Stueck::19527.html | M3 x 30mm socket head screw | 4 | € 1.20
https://www.modell-hubschrauber.at/Schrauben-Unterlegscheiben-Muttern-Bauzubehoer/Muttern-Stoppmuttern/Stoppmuttern-M3-10Stueck::19548.html | M3 self-locking nut | 17 | € 5.08
https://www.modell-hubschrauber.at/Schrauben-Unterlegscheiben-Muttern-Bauzubehoer/Unterlegscheiben/Unterlegscheiben-galvanisiert-M2-10Stueck::22310.html | M2 washer | 24 | € 3.58
https://www.modell-hubschrauber.at/Schrauben-Unterlegscheiben-Muttern-Bauzubehoer/Unterlegscheiben/Unterlegscheiben-galvanisiert-M3-10Stueck::22312.html | M3 washer | 41 | € 6.11
https://www.pollin.at/p/econ-connect-pfostenverbinder-din-41651-10-polig-grau-rm-2-54-mm-453341 | female box header | 1 | € 0.17
https://www.pollin.at/p/econ-connect-wannenstecker-din-41651-10-polig-schneidklemm-rm-2-54-mm-453345 | male box header | 1 | € 0.59
https://www.proshop.at/Ferngesteuert/FlySky-Receiver-FS-A8S/3248332 | RC receiver | 1 | € 14.90
https://www.prusa3d.com/de/produkt/prusament-pc-blend-carbon-fiber-black-800g-6/ | PC CF spool | 1 | € 65.99
https://www.prusa3d.com/product/prusament-petg-prusa-orange-1kg/ | PETG spool | 1 | € 32.99
https://www.reichelt.at/at/de/shop/produkt/flachbandkabel_awg28_10-pol_grau_3m-ring-47637 | ribbon cable |  | € 0.15
https://www.rotorama.de/product/gemfan-sl-5125-3-t | propeller | 6 | € 4.49
https://www.rotorama.de/product/gnb-1850mah-6s-140c | LiPo Battery | 1 | € 45.39
https://www.rotorama.de/product/micoair-h743-v2 | FCU | 1 | € 52.69
https://www.rotorama.de/product/readytosky-xt30-s-kabelem-male | XT30 connector | 2 | € 3.98
https://www.rotorama.de/product/rotorama-battery-strap-pogumovany-kevlar-20x250 | battery strap | 1 | € 1.99
https://www.rotorama.de/product/skystars-ko50a-bls | ESC | 2 | € 88.78
https://www.rotorama.de/product/sroub-s-valcovou-hlavou-m2-10ks | M2 x 8mm socket head screw | 12 | € 1.43
https://www.rotorama.de/product/tlusta-silikonova-podlozka-pod-baterii-10ks | silicone pad | 1 | € 0.40
Total Result |  | 205 | € 570.13

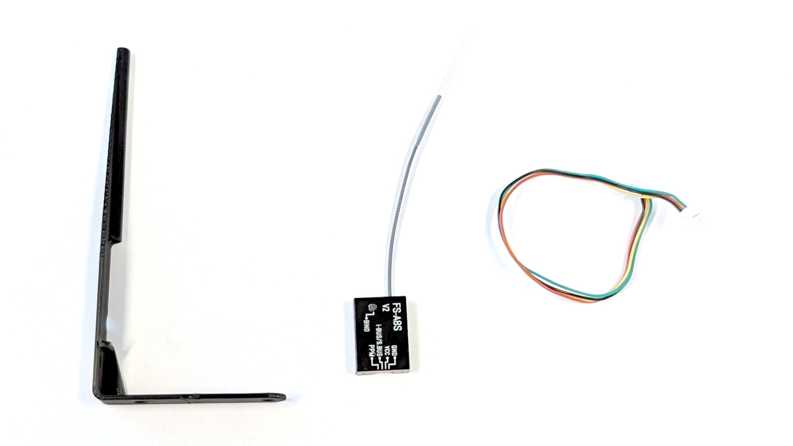
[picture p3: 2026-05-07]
docs/assets/images/parts_rc_receiver.jpg

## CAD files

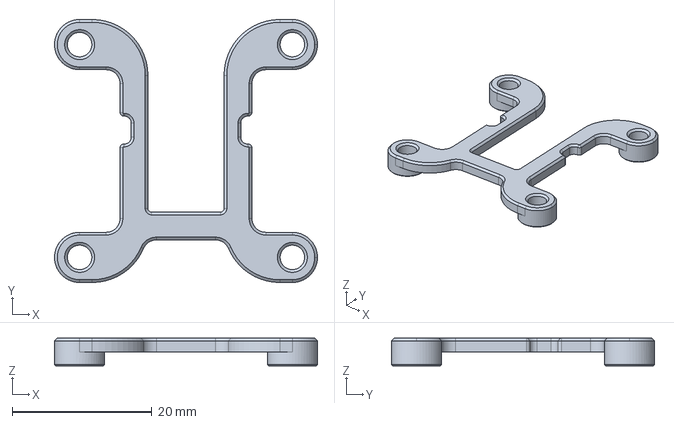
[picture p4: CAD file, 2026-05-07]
mechanical/exports/step/capacitor_holder.step
37.7 x 37.7 x 4.00 mm

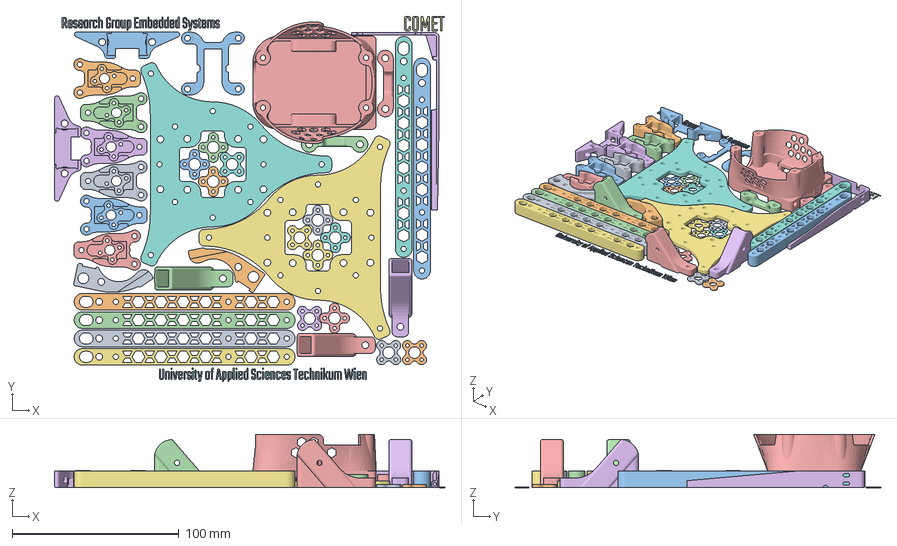
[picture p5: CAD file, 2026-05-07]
mechanical/prints/prusaslicer/COREONE/PC-CF/frame-PC-CF-0.20-PrusaCOREONE-0.4.3mf
234.1 x 219.3 x 32.0 mm
motor_mount.stl
motor_mount_1mm_spacer.stl
motor_mount_2mm_spacer.stl
capacitor_holder.stl
landing_gear_mount.stl
rotor_arm.stl
battery_holder.stl
rc_receiver_mount.stl
mounting_plate.stl
xt30_male_mount.stl
esc_connector_mount.stl x 2
quick_release_base.stl
Text - comet
uastw
embsys

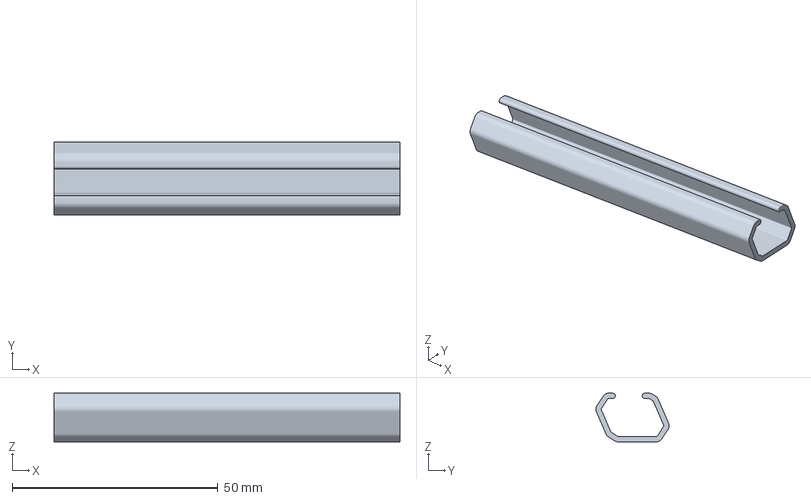
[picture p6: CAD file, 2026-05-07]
mechanical/prints/prusaslicer/COREONE/PETG/color-coding-PETG-0.20-PrusaCOREONE-0.4.3mf
84.0 x 17.8 x 11.8 mm

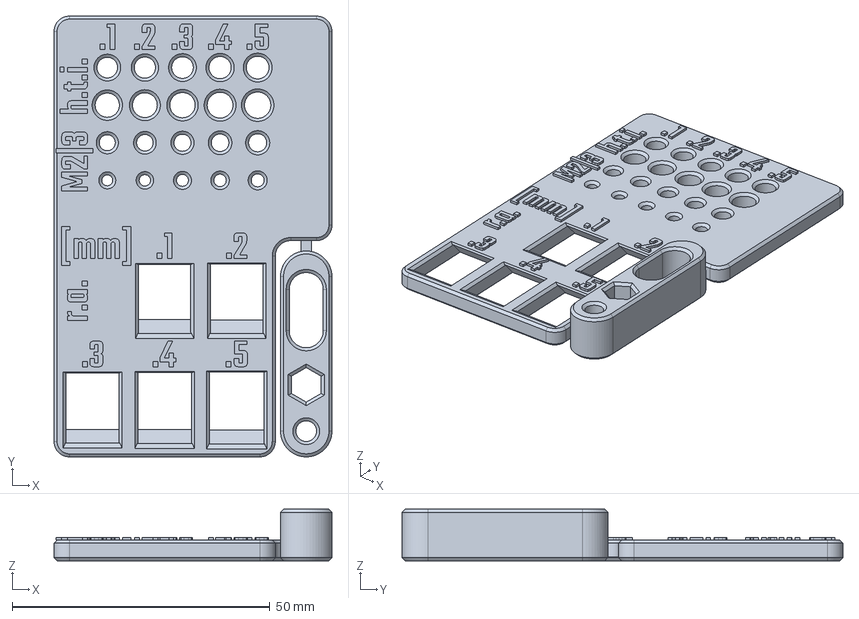
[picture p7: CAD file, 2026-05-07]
mechanical/source/calibration/clearance_gauge.FCStd
54.0 x 85.6 x 10.0 mm

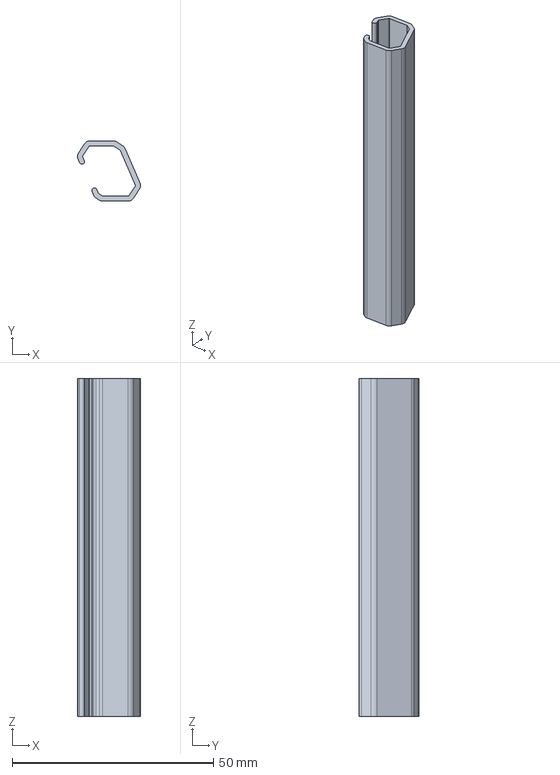
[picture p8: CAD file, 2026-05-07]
mechanical/source/parts/remote_label.FCStd
15.7 x 15.0 x 84.0 mm

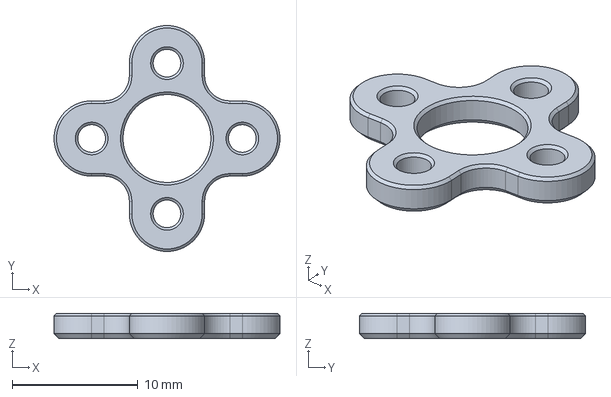
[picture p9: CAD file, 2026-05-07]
mechanical/exports/step/motor_mount_2mm_spacer.step
18.0 x 18.0 x 2.00 mm

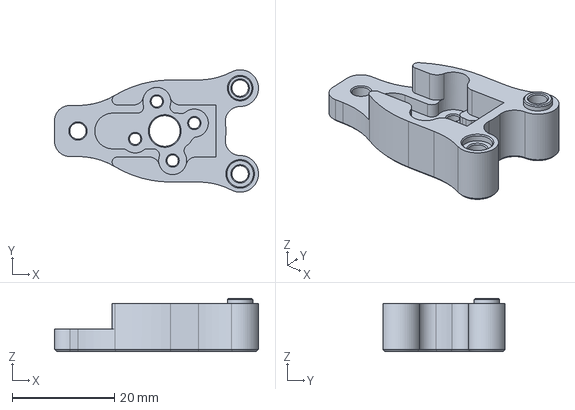
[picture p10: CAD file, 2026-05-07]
mechanical/exports/step/motor_mount.step
40.0 x 24.0 x 10.4 mm

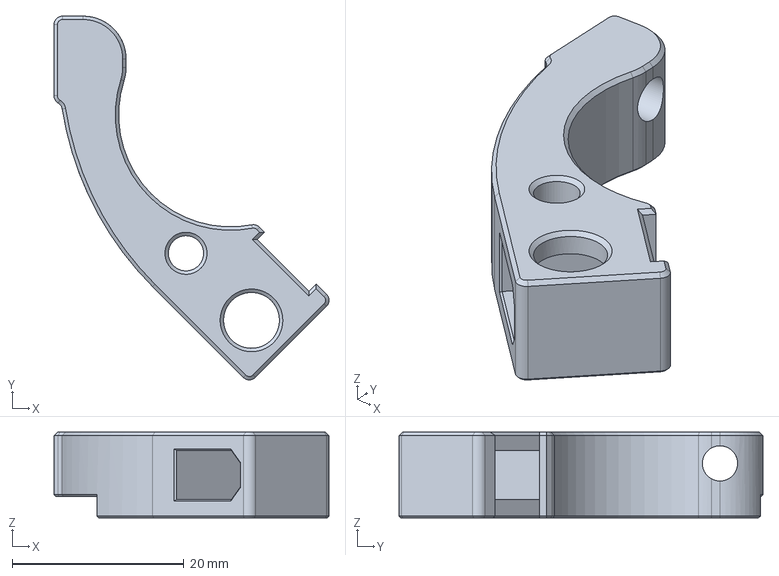
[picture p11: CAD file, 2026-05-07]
mechanical/exports/step/xt30_male_mount.step
32.0 x 42.4 x 10.0 mm

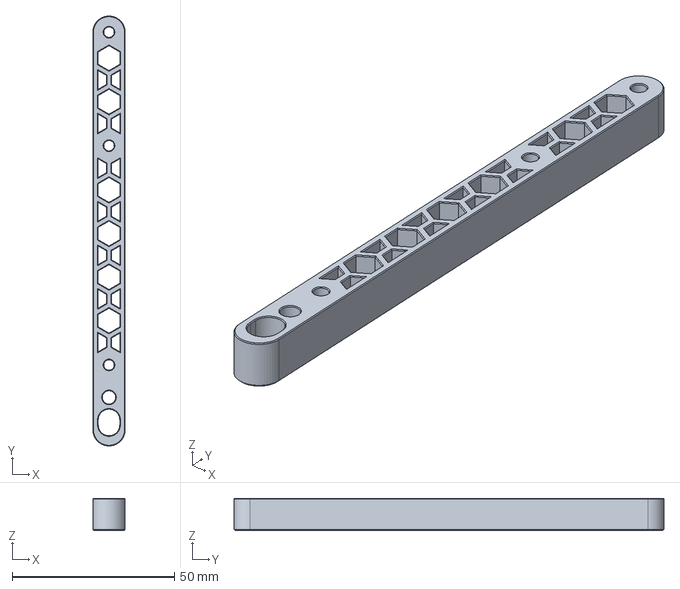
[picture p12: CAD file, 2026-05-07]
mechanical/exports/step/rotor_arm.step
10.0 x 132.6 x 10.0 mm

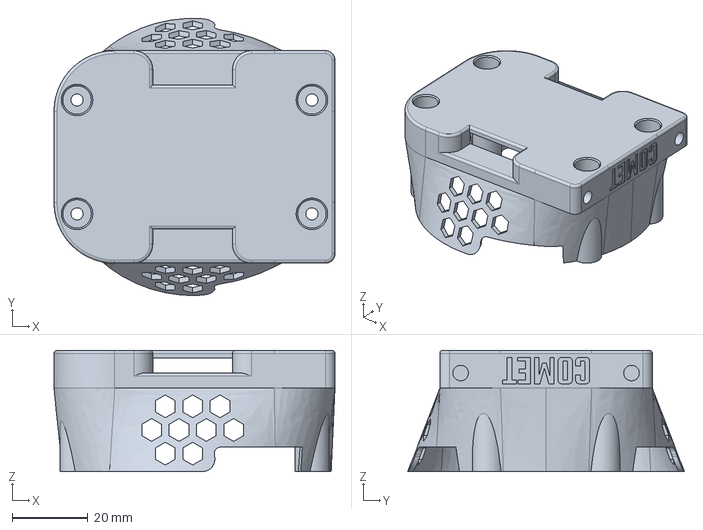
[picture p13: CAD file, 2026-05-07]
mechanical/exports/step/battery_holder.step
74.0 x 73.0 x 32.0 mm

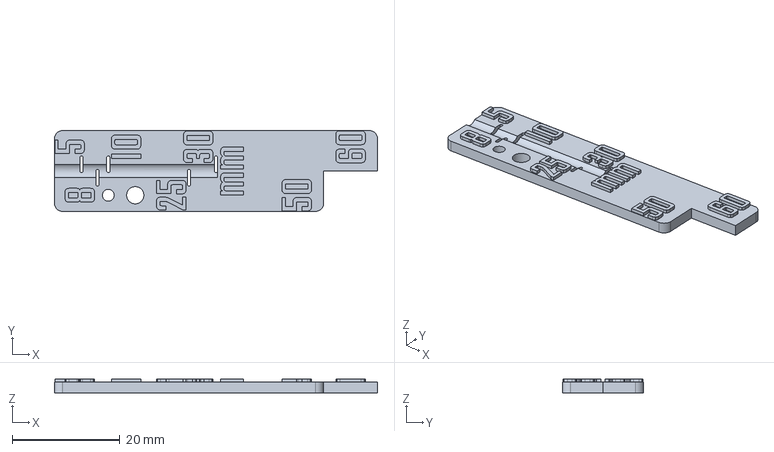
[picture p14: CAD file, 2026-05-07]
mechanical/exports/step/length_ruler.step
60.0 x 15.0 x 2.60 mm

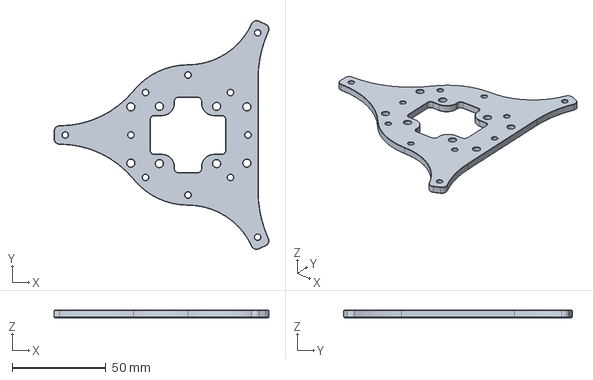
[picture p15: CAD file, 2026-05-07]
mechanical/exports/step/mounting_plate.step
114.6 x 122.1 x 4.00 mm

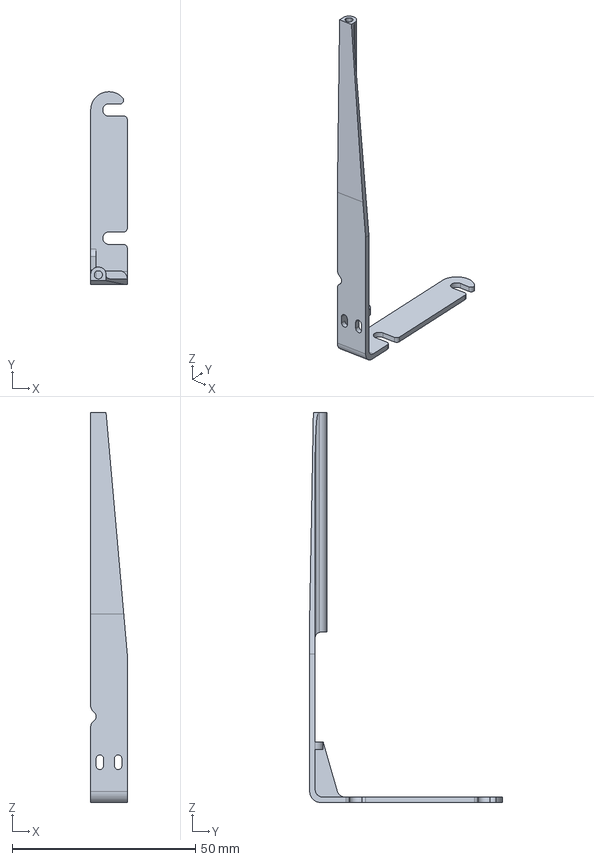
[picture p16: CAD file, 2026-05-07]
mechanical/exports/step/rc_receiver_mount.step
10.0 x 52.6 x 106.5 mm

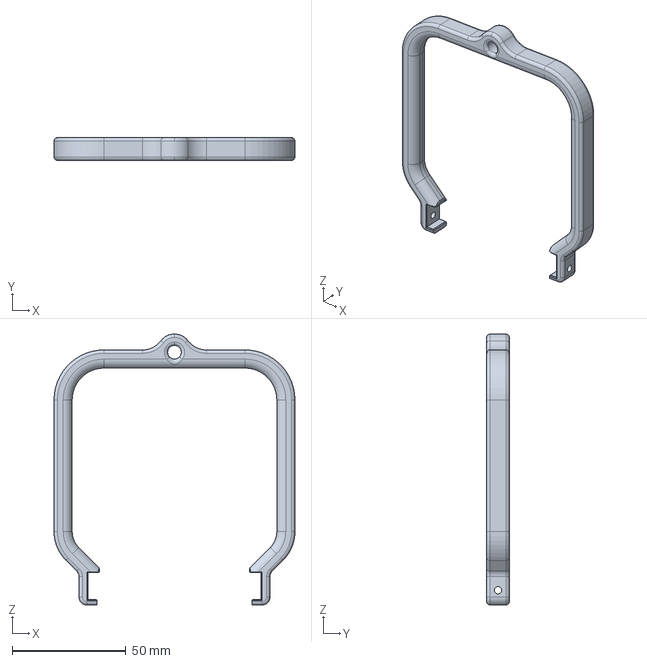
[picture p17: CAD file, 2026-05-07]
mechanical/exports/step/handle.step
106.0 x 10.0 x 119.2 mm

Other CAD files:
mechanical/prints/prusaslicer/COREONE/PC-CF/clearance-gauge-PC-CF-0.20-PrusaCOREONE-0.4.3mf
mechanical/exports/step/clearance_gauge.step
mechanical/exports/step/quick_release_base.step
mechanical/exports/step/motor_mount_1mm_spacer.step
mechanical/exports/step/esc_connector_mount.step
mechanical/exports/step/landing_gear_mount.step
mechanical/exports/stl/battery_holder.stl
mechanical/exports/stl/capacitor_holder.stl
mechanical/exports/stl/clearance_gauge.stl
mechanical/exports/stl/esc_connector_mount.stl
mechanical/exports/stl/handle.stl
mechanical/exports/stl/landing_gear_mount.stl
mechanical/exports/stl/length_ruler.stl
mechanical/exports/stl/motor_mount.stl
mechanical/exports/stl/motor_mount_1mm_spacer.stl
mechanical/exports/stl/motor_mount_2mm_spacer.stl
mechanical/exports/stl/mounting_plate.stl
mechanical/exports/stl/quick_release_base.stl
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

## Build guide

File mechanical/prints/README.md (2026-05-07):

DESCRIBE NAMING CONVENTION OF 3D PRINT FILES

# PrusaSlicer assets

This folder contains PrusaSlicer project files and presets for printing the drone parts reproducibly.

Use these assets to import a ready-to-print configuration bundle, or pick per-printer/per-material presets and 3MF projects with saved orientations, supports, and modifier meshes.

Build: PrusaSlicer-2.9.4+flathub.org

## Contents

- bundle: prusaslicer-bundle-v1.ini        # All-in-one bundle for quick import
- printers/, filaments/, print-profiles/
  - Individual presets (.ini) you can import selectively.
- projects/
  - Per-part PrusaSlicer projects (.3mf) with locked orientation, supports, and modifiers.
- plates/ (optional)
  - Multi-part plates for batch printing spares.
- gcode/ (optional)
  - Pre-sliced G-code for specific machines/profiles. See safety note.
- screenshots/
  - Reference images showing part orientation, supports, and modifiers.

Naming convention: PART__PRINTER__MATERIAL__LAYERHEIGHT__vREV.EXT
- Example: ARM-L__MK4__PETG__0p20__v1.3mf

## Requirements

- PrusaSlicer ≥ 2.6 (or SuperSlicer recent release)
- Nozzle size: 0.4 mm unless stated otherwise in filename or project notes
- Verified printers: list your tested machines here (e.g., Prusa MK4, MK3S+, Bambu X1C via generic profile)

## Quick start: Import the full config bundle

1) Open PrusaSlicer.
2) File → Import → Import Config Bundle…
3) Select bundles/OpenPrintDrone_bundle.ini.
4) In the top toolbar, choose:
   - Printer: pick the imported printer profile (e.g., Prusa MK4 0.4).
   - Filament: choose the intended filament (e.g., PETG Generic).
   - Print Settings: choose the matching quality (e.g., 0.20mm QUALITY).
5) File → Open Project… and pick a 3MF from projects/ (e.g., ARM-L__MK4__PETG__0p20__v1.3mf).
6) Confirm that:
   - The printer, filament, and print settings match the 3MF filename.
   - Nozzle size and layer height are correct.
   - Supports/modifiers are present as shown in screenshots/.

Then slice and review the preview (top layers, bridges, support interfaces) before exporting G-code.

## Alternative: Import individual presets

If you prefer not to import a full bundle:

- Import printer preset:
  - File → Import → Import Config… → select a .ini from printers/
- Import filament preset:
  - File → Import → Import Config… → select a .ini from filaments/
- Import print profile:
  - File → Import → Import Config… → select a .ini from print-profiles/
- Open a part project from projects/ and ensure the three selectors (Printer, Filament, Print Settings) are set to the intended presets.

## Material guidance (recommendations)

- Arms and structural parts: PETG or PA-CF/Nylon (for higher heat and stiffness). PA-CF requires a dry filament and preferably an enclosure.
- Camera/FPV damped parts: TPU (use dedicated flexible print profile).
- Plates/covers: PETG or PLA+ if thermals are low; prefer PETG for field durability.

Typical baseline settings (override as needed in your profiles):
- Perimeters: 4–6 on arms; 3–4 on covers.
- Infill: 20–35% grid/gyroid for covers; 40–60% for arms; increase sparse infill overlap to strengthen walls.
- Supports: Only where needed; interface layers enabled; avoid supports inside insert holes.
- Holes for M3: model nominal 3.0–3.1 mm, then drill/ream to 3.2 mm post-print for best fit.

## Orientation and supports

- Use the provided 3MF orientation; it is chosen to:
  - Align layer lines with load paths on arms.
  - Keep insert bosses vertical to reduce ovalization.
  - Minimize supports in critical surfaces.
- See screenshots/ for each part’s preview and support strategy.
- If you change orientation, review:
  - Bridge cooling, overhang quality, and strength along layer lines.

## Heat-set inserts and post-processing

- Heat-set inserts (e.g., M3):
  - Recommended tip temp: follow insert manufacturer (typically 250–280 °C for PETG, lower for PLA).
  - Use a printed alignment jig if included; press vertically without twisting.
- Hole finishing:
  - Clear pilot holes with a 3.0 mm drill; ream to 3.2 mm for M3 clearance if required.
- Threaded holes:
  - If tapping printed threads, reduce tapping torque and back off frequently to avoid delamination.

## Using optional G-code (if present)

- Provided G-code is for a specific machine and profile at the time of release.
- You MUST verify:
  - Bed and nozzle temperatures suit your filament brand.
  - Start/end G-code matches your printer (bed leveling, purge lines, flow calibration).
  - Fan, chamber, and accessory controls are correct for your hardware.
- If in doubt, re-slice from the 3MF using your known-safe profiles.

## Safety and liability notice

- 3D printers and UAVs can cause injury and property damage.
- Always:
  - Supervise prints; ensure proper ventilation for materials that emit fumes.
  - Validate temperatures, speeds, and adhesives on your hardware.
  - Inspect printed parts for defects, poor layer adhesion, or warping before flight.
  - Use threadlocker where indicated; torque fasteners per the build manual.
  - Follow local regulations for UAV operation; perform ground checks and a gentle maiden flight.
- Any G-code and settings are provided without warranty; you assume responsibility for safe operation.

## Versioning and compatibility

- 3MF and presets are versioned to match hardware releases (e.g., v1.0.0).
- If a part geometry or critical setting changes, the filename revision (vX) increases.
- Check CHANGELOG.md for notes affecting print settings or orientation.

## Troubleshooting

- Layers splitting or weak arms:
  - Dry filament thoroughly; increase nozzle temperature by 5–10 °C; add perimeters; consider higher enclosure temperature.
- Insert holes too tight/loose:
  - Ream to size after printing; adjust “hole_xy_compensation” in the print profile; use the tolerance test coupon if provided.
- Stringing or blobs:
  - Reduce nozzle temp slightly; tune retraction; enable wipe and coasting if compatible with your printer.
- Overly long print times:
  - Switch to SPEED profile or 0.28 mm layers where acceptable; maintain perimeters for strength.

## How to contribute

- For new printers/filaments:
  - Export your tuned presets (.ini) and a sample 3MF for one part.
  - Follow the naming convention and place files in the appropriate subfolders.
  - Add a short note to this README under “Verified printers” and open a pull request.
- Large binary files:
  - .3mf and .gcode should be tracked with Git LFS.
  - Example .gitattributes entries:
    ```
    *.3mf filter=lfs diff=lfs merge=lfs -text
    *.gcode filter=lfs diff=lfs merge=lfs -text
    ```

## Links

- Printing notes and per-part tips: link to docs/printing/part-notes.md
- Build manual: link to docs/build-manual/
- Issue tracker for print problems: link to repository issues

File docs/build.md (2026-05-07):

<!-- SPDX-License-Identifier: CC-BY-SA-4.0 -->

# Build Manual

## Table of Contents

- [Preparation](#preparation)
  - [Bill of Materials](#bill-of-materials)
  - [Tools](#tools)
  - [3D Print](#3d-print)
- [The Build](#the-build)
  - [Motor Block](#motor-block)
    - [MR30 Connector](#mr30-connector)
    - [Mounting the Motors](#mounting-the-motors)
    - [Mechanical Assembly](#mechanical-assembly)
  - [ESC Stack](#esc-stack)
    - [ESC Connector Cable](#esc-connector-cable)
    - [Combining ESCs](#combining-escs)
  - [Landing Gear](#landing-gear)
    - [Preparation of Parts](#preparation-of-parts)
    - [Mechanical Assembly](#mechanical-assembly-1)
  - [Battery Holder](#battery-holder)
    - [Preparation of Parts](#preparation-of-parts-1)
    - [Mechanical Assembly](#mechanical-assembly-2)
  - [RC Receiver](#rc-receiver)
    - [Connector Modification](#connector-modification)
    - [Preparation RC receiver](#preparation-rc-receiver)
    - [Mechanical Assembly](#mechanical-assembly-3)
  - [Y Frame](#y-frame)
    - [Preparation of Parts](#preparation-of-parts-2)
    - [Assembly top Mounting Plate](#assembly-top-mounting-plate)
    - [Assembly bottom Mounting Plate](#assembly-bottom-mounting-plate)
    - [Mechanical Assembly](#mechanical-assembly-4)
  - [Putting COMET together](#putting-comet-together)
    - [Adding the Landing Gear](#adding-the-landing-gear)
    - [Adding the Motor Blocks](#adding-the-motor-blocks)
    - [Adding the ESC Stack](#adding-the-esc-stack)
    - [Adding the Battery Holder](#adding-the-battery-holder)
    - [Adding the RC receiver](#adding-the-rc-receiver)
    - [Adding the Handle](#adding-the-handle)
  - [Final Checks](#final-checks)
- [Finished Build](#finished-build)

## Preparation

The first step is to prepare all the necessary parts and tools. This includes ordering materials, 3D printing the frame, post-processing the prints, and gathering the necessary tools.

[Back to the top &#8593;](#table-of-contents)

### Bill of Materials

The [bill of materials](/../bill_of_materials.ods) lists all the necessary parts and their locations on COMET. The *shopping list* register shows the quantity of each part needed, and the source column indicates where the parts can be ordered.

[Back to the top &#8593;](#table-of-contents)

### Tools

The following is a list of the tools needed to build COMET:
- length ruler (from the 3D-printed frame parts)
- side cutter
- nose plier
- soldering iron, solder, and flux
- 1.5mm allen key
- 2.5mm allen key
- 5.5mm open-jaw wrench
- tweezers
- zip ties (different sizes)
- shrinking tube (different sizes)
- (optional) cable striper
- (optional) threaded inserts melting [aid set](https://www.3djake.com/ruthex/soldering-tips-melting-aid-set?similar_products_d_a=30899)

[Back to the top &#8593;](#table-of-contents)

### 3D Print

ADD THE CALIBRATION PROCEDURE!

In the [prints/](/../../mechanical/prints/) (computer-aided manufacturing) folder, select the printer that will be used to print the frame and/or accessory components. These folders contain the project files for the slicing software (converting 3D models into 3D printable objects). The print files are located in the printer's *gcode folder*. Select the appropriate material. The files named *comet_single_plate_...* refer to the complete frame; *comet_propeller_guards_...* are for printing a set of propeller guards only; and *comet_color-coding_accessories_...* are for printing non-functional pieces to distinguish between different setups.
<div align="center">
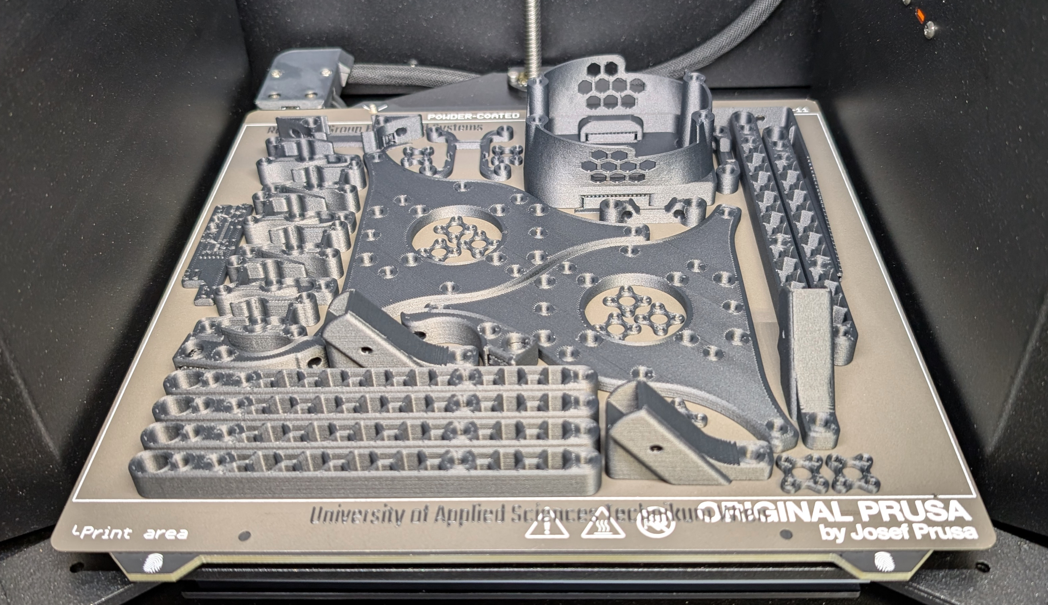
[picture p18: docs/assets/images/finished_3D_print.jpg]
    
    <p>Fig. 1. The finished 3D-printed frame parts were produced using our research group's Prusa CORE One 3D printers. This build plate contains all the parts needed to assemble COMET.</p>
</div>

The 3D-printed frame requires the removal of support structures before proceeding. This concerns components battery holder (BH-01), XT30 connector mounts (YF-03), and ESC connector mount (YF-04). The figure below highlights these structures, which can be detached by applying a small amount of force with nose pliers.
<div align="center">
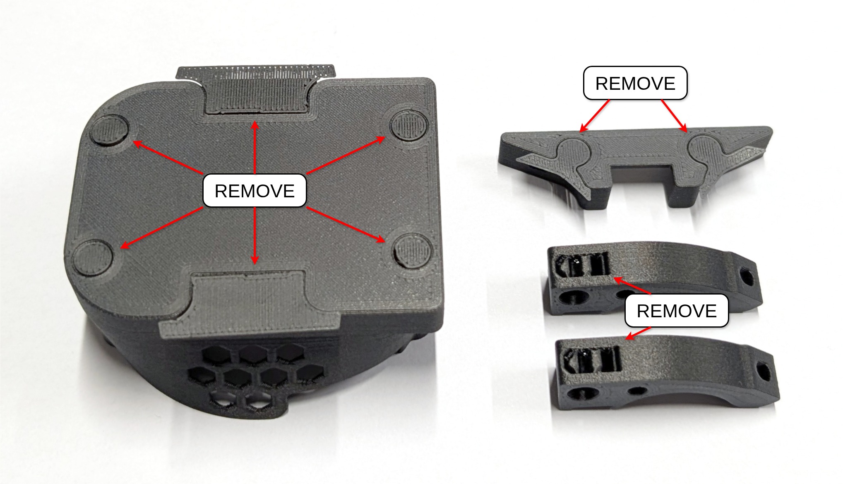
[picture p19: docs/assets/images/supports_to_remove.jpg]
    
    <p>Fig. 2. Spots where the supports need to be removed.</p>
</div>

Additionally, the 3D print includes a ruler to measure the size of all the screws used in the build. Use it to ensure that you use the proper size screw for the task at hand.
<div align="center">
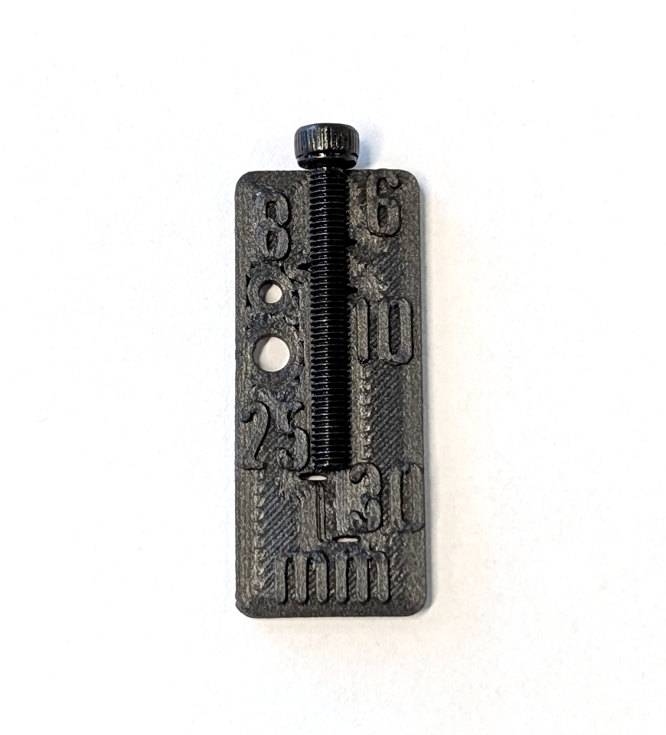
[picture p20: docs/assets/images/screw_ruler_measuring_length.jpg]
    
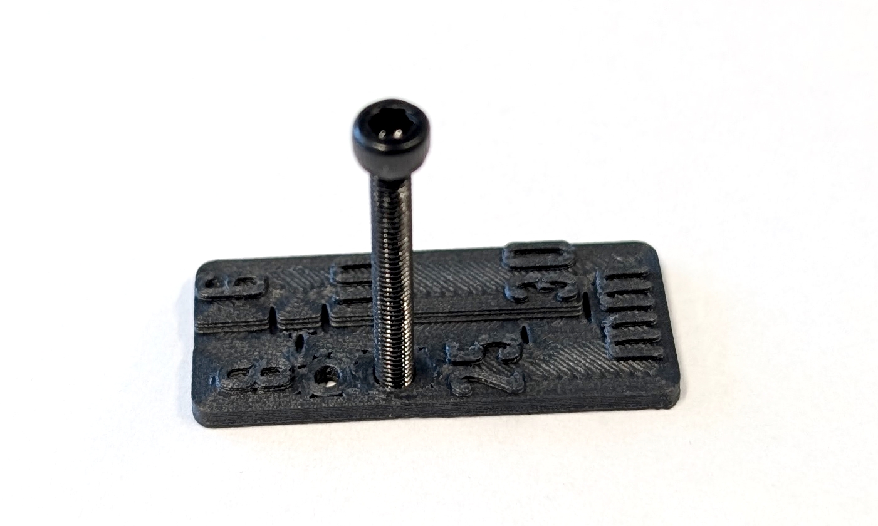
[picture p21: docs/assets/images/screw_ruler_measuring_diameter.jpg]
    
    <p>Fig. 3. Here is an example of how to measure the length (left) and diameter (right) of a screw.</p>
</div>

[Back to the top &#8593;](#table-of-contents)

## The Build

At the beginning of the assembly process, gather all the necessary components and tools. The assembly process is divided into subgroups that come together to form the complete drone.
<div align="center">
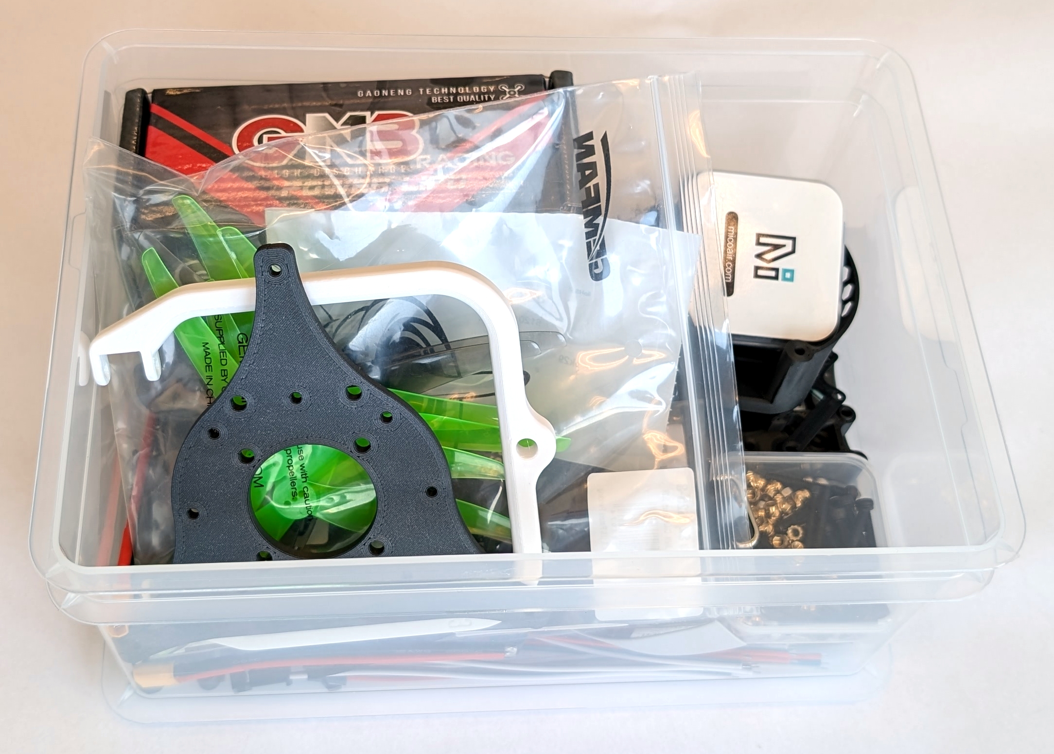
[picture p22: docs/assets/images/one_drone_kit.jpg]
    
    <p>Fig. 4. Pre-built student kit for the EDUCON 2026 paper submission. The displayed parts may differ from the latest version of COMET.</p>
</div>

[Back to the top &#8593;](#table-of-contents)

### Motor Block

To assemble a full hexacopter setup in a Y configuration, three motor blocks are required. These connect the motors and propellers to the drone, making it possible to control the aircraft. All parts for this subgroup are labeled with the prefix "MB-*" in the [bill of materials](./bill_of_materials.ods). The following steps show how to assemble one motor block.
<div align="center">
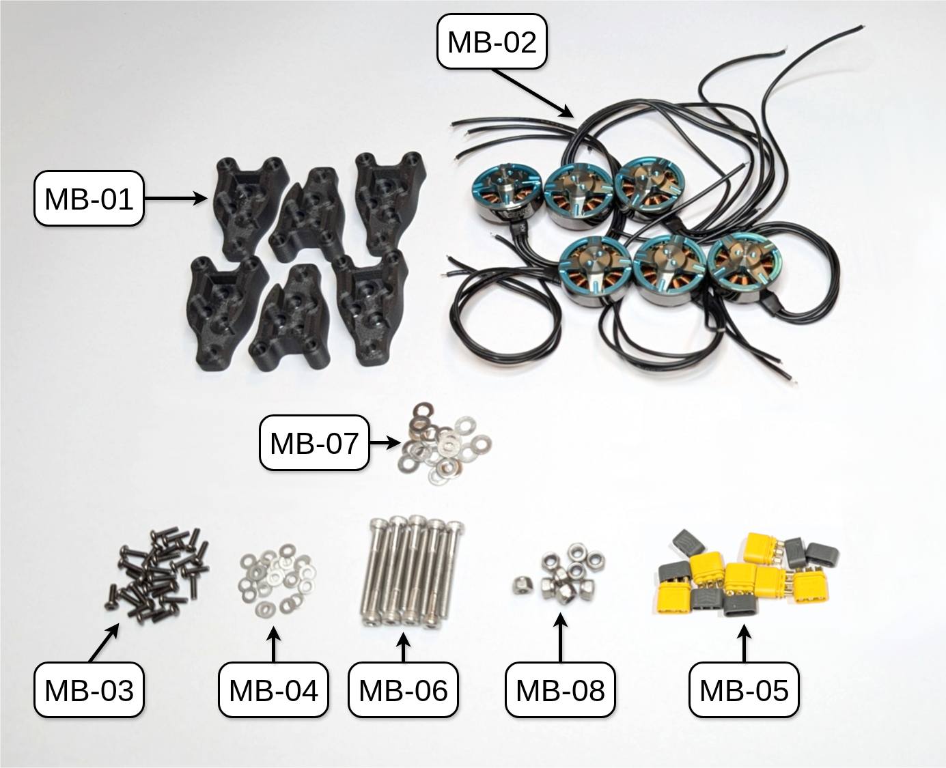
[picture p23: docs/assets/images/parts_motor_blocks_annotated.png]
    
    <p>Fig. 5. All parts needed to build the three motor blocks of COMET.</p>
</div>

[Back to the top &#8593;](#table-of-contents)

#### MR30 Connector

All brushless DC (BLDC) motors are connected to their respective electronic speed controllers (ESCs) via MR30 connectors, which are common in the drone community. First, attach the male MR30 connectors (MB-05, the ones with the pins inside the connector) to the BLDC motors (MB-01). Then, use a measuring tape or the supplied length ruler to cut the motors' cables to a length of around 5cm from the motor hub.
<div align="center">
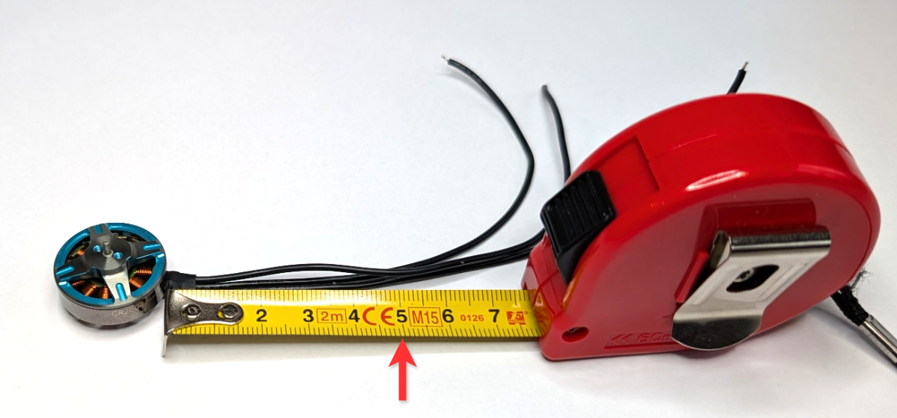
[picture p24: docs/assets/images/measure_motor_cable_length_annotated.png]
    
    <p>Fig. 6. Cut each motor cable to a length of around 5cm.</p>
</div>

After cutting the cables to the appropriate length for each motor, remove approximately 3mm of insulation from each cable and apply solder to the exposed copper wire.
<div align="center">
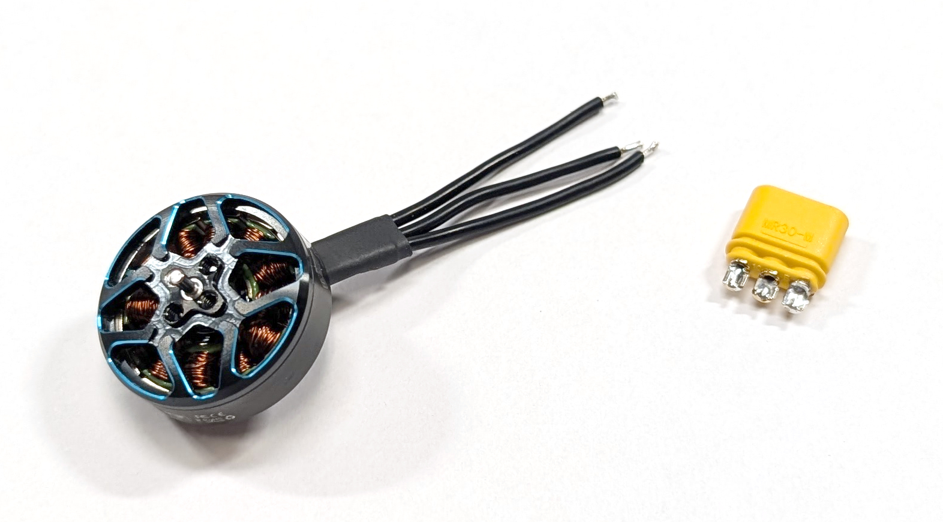
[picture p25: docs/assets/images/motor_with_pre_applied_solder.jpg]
    
    <p>Fig. 7. One motor with three exposed copper wire and pre-applied solder.</p>
</div>

After completing the previous step, insert the three motor cables through the solder cover (the gray piece) of the male MR30 connector (MB-05). Then, apply a small amount of solder to the solder cup (the yellow or orange piece) of the connector. Next, align one of the exposed pieces of each motor wire with a solder cup on the connector and solder them together. Make sure there are no shorts between the wires or connectors. The order of the cables does not matter because the spin direction of the motor can be set either in software or by physically switching two cables (BLDC phases) at the ESC. The latter option will be explained further in a later section.
<div align="center">
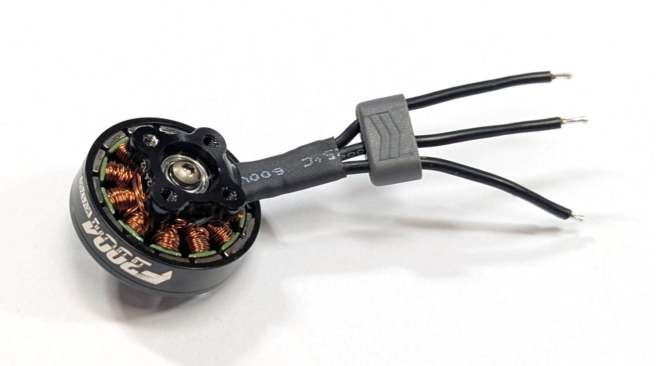
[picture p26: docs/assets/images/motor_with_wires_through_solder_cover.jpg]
    
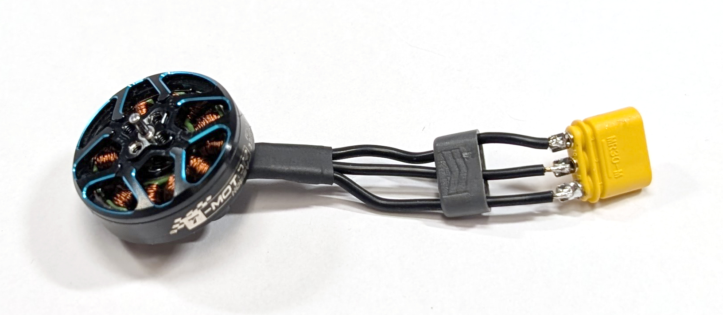
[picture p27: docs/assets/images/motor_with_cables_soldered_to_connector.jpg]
    
    <p>Fig. 8. (left) One motor with its wires put through the solder cover and (right) these wires soldered to the male MR30 connector.</p>
</div>

Test the solder joint by gently pulling on the connector and cable. Then, push the solder cover onto the connector until it clicks into place.
<div align="center">
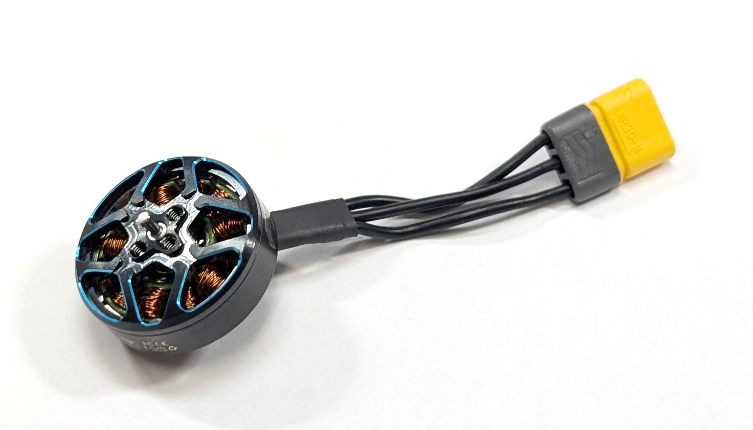
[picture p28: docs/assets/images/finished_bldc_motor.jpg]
    
    <p>Fig. 9. One BLDC motor electrically wired.</p>
</div>

Put the propellers (MB-09) and M2 x 8mm screws (MB-10) aside for later propeller mounting.

[Back to the top &#8593;](#table-of-contents)

#### Mounting the Motors

After attaching the male MR30 connectors to the BLDC motors, assemble the motor blocks. Begin with the six motor block halves. Mount the BLDC motor (MB-02) to the motor mount (MB-01) using the M2 x 5mm screws and washers (MB-03 and MB-04). If the motors only come with M2 x 6mm or M2 x 7mm screws, add an appropriate motor mount spacer between the motor and the mount. Ensure that the BLDC motor aligns with the mounting holes, allowing its cables to angle slightly to the left (see Fig. 10, right image). Before tightening the screws, verify that they do not touch the motor windings. All steps are depicted in Fig. 10 for clarity. Figure 11 shows an assembled motor block half for reference.
<div align="center">
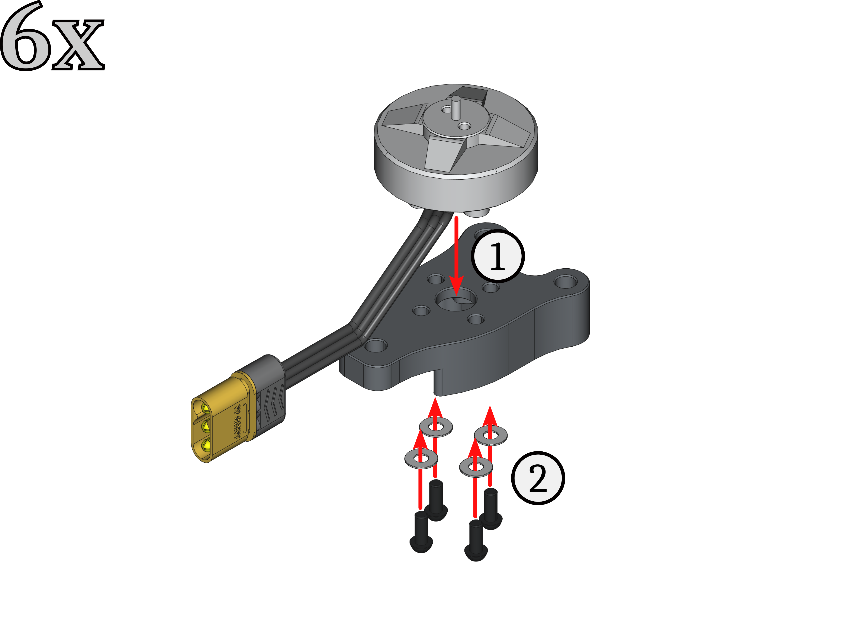
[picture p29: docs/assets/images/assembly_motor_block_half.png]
    
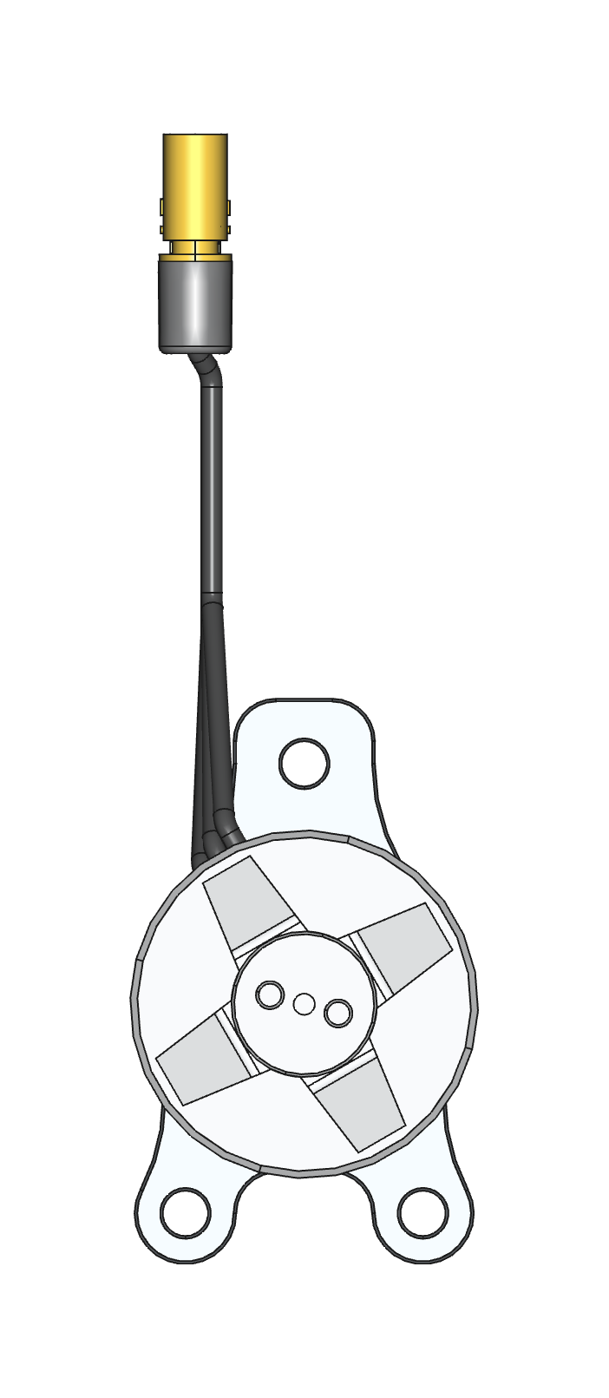
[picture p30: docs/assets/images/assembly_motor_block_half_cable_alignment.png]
    
    <p>Fig. 10. (left) Assembly steps for one motor block half, with (right) the cables angling slightly to the left.</p>
</div>
<div align="center">
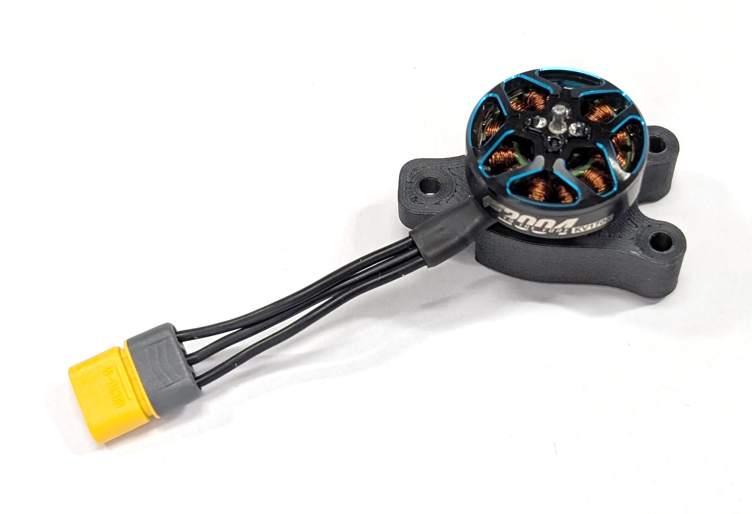
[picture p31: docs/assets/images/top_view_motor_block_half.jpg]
    
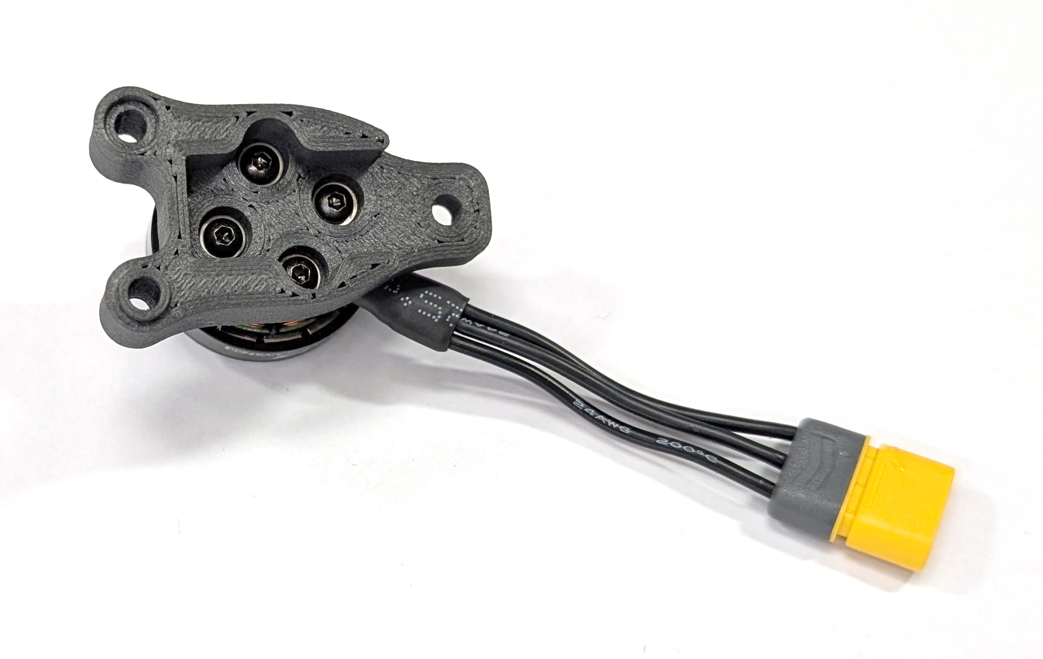
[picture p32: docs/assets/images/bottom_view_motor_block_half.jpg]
    
    <p>Fig. 11. One assembled motor block half: (left) top view; (right) bottom view.</p>
</div>

[Back to the top &#8593;](#table-of-contents)

#### Mechanical Assembly

Next, take two motor block halves and screw them together using two M3 x 25mm screws (MB-06), four M3 washers (MB-07), and two M3 self-locking nuts (MB-08). All involved steps are depicted in Fig. 12. These steps need to be repeated three times, resulting in three fully assembled motor blocks ready for use.
<div align="center">
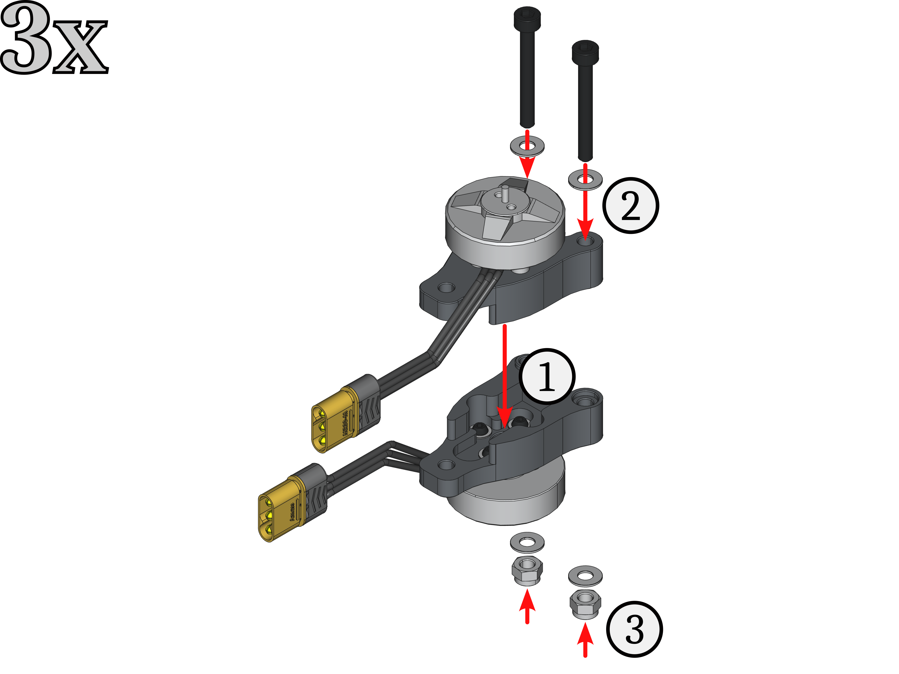
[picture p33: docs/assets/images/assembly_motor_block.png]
    
    <p>Fig. 12. Assembly steps to put two motor block halfs together.</p>
</div>
<div align="center">
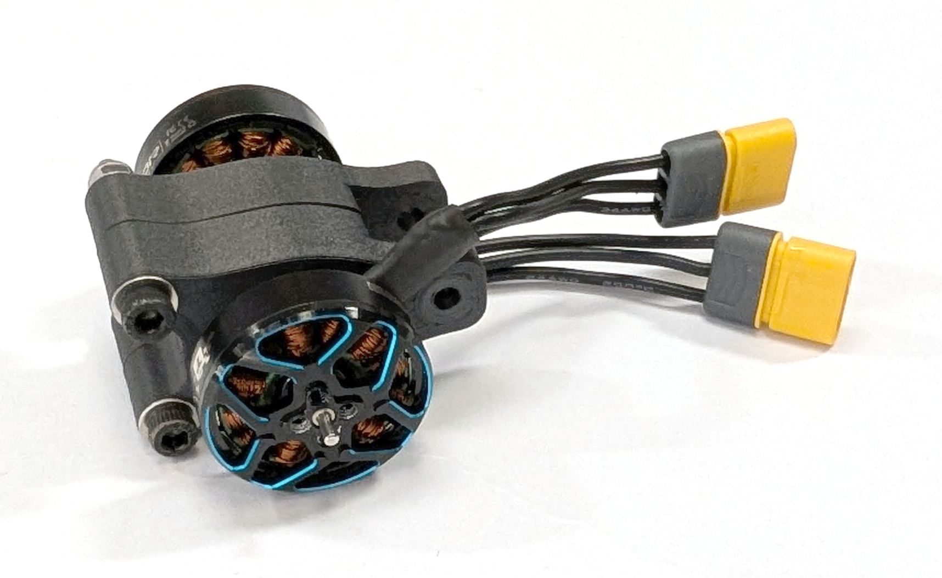
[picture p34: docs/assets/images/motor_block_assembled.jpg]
    
    <p>Fig. 13. One fully assembled motor block.</p>
</div>

Store the remaining M3 x 25mm screws (MB-06), M3 washers (MB-07), and M3 self-locking nuts (MB-08) for the final assembly.

[Back to the top &#8593;](#table-of-contents)

### ESC Stack

Electronic speed controllers (ESCs) are vital components of the drone because they control the BLDC motors and keep the drone airborne. These ESCs are accessible via a standardized IDC connector connected to the FCU, which supplies power to the FCU too. All parts for this subgroup are labeled with the prefix "ES-*" in the [bill of materials](./bill_of_materials.ods). The following steps illustrate how to assemble the COMET ESC stack. If the ESCs do not have rubber vibration dampers, install them first, placing the short end on the JST connector side!
<div align="center">
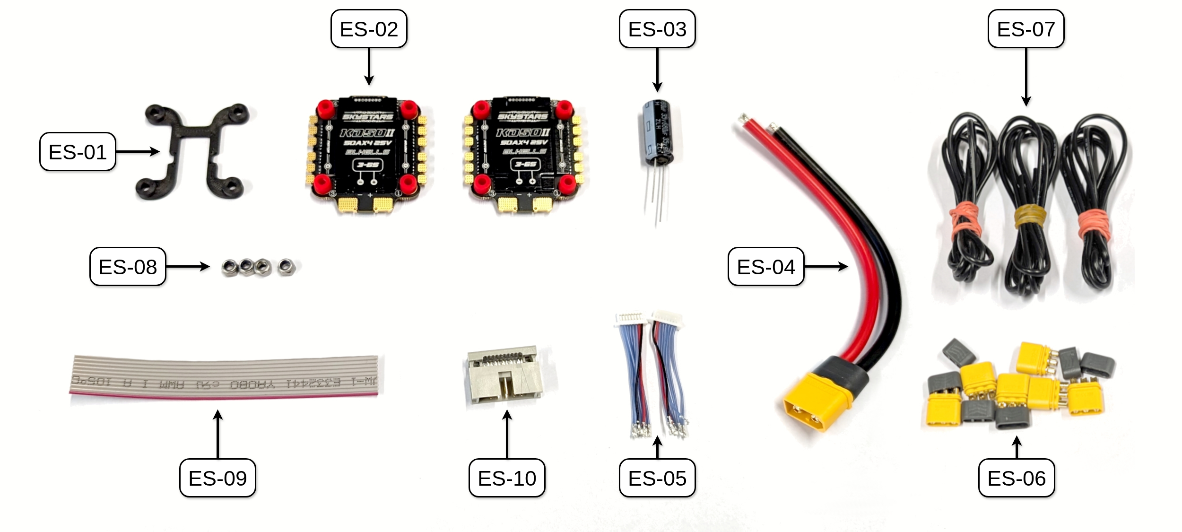
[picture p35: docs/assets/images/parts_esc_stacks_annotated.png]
    
    <p>Fig. 14. All parts needed to build the ESC stack.</p>
</div>

[Back to the top &#8593;](#table-of-contents)

#### ESC Connector Cable

First, we need to manufacture the ESC cable that connects both ESCs through the JST SH connectors with the FCU. The ESC closer to the capacitor and mounting plate is called ESC #1, and the one below it is called ESC #2 (as indicated with the positioning in Fig. 15).
<div align="center">
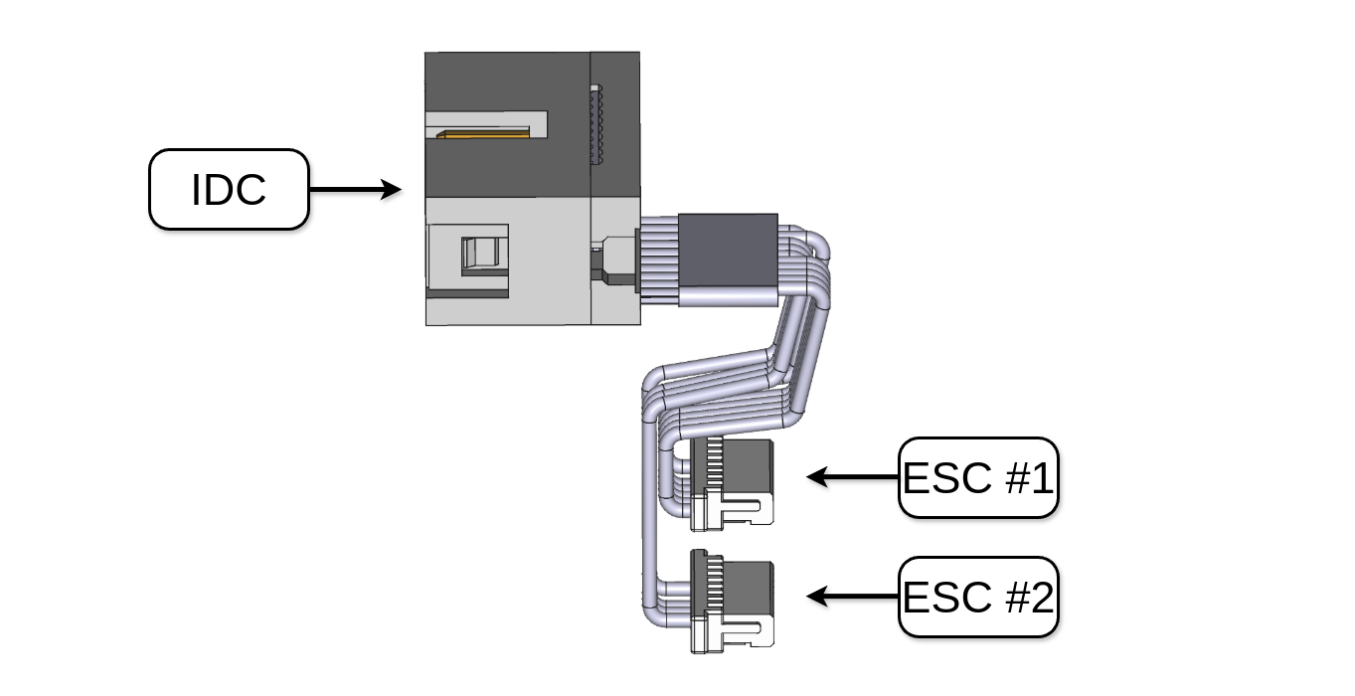
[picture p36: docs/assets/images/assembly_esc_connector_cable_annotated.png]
    
    <p>Fig. 15. Reference for the ESC connector cable.</p>
</div>

Fig. 16 shows the pinouts for the COMET IDC connector (ES-10) and the JST SH connector of the chosen [Skystars KO50A BLS](https://www.rotorama.de/product/skystars-ko50a-bls) 4-in-1 ESCs (ES-05). Attention: Make sure you have the correct pinout for your ESC connector because the current measurement pin and N.C. (or telemetry signal) may be switched in some cases. This is the case for [SpeedyBee](https://www.speedybee.com/speedybee-f405-bls-50a-30x30-4-in-1-esc) ESCs. Please refer to the respective user manuals for more information!
<div align="center">
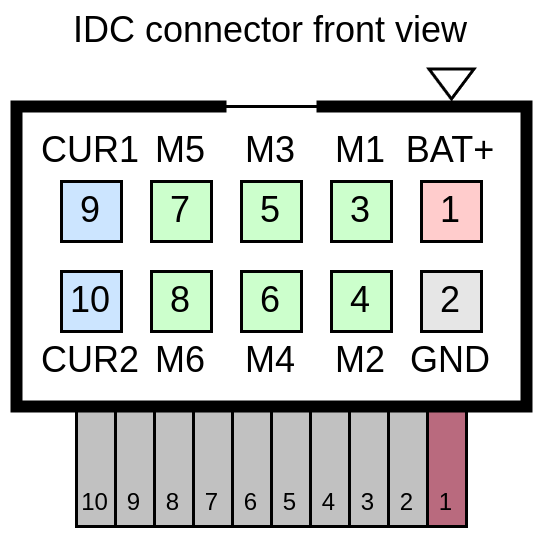
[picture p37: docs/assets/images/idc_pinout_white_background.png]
    
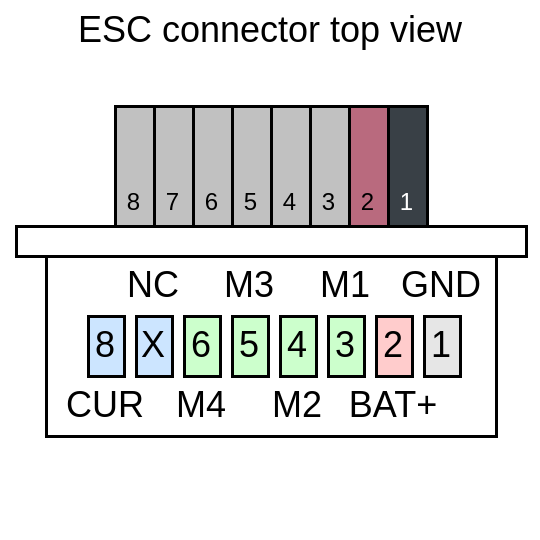
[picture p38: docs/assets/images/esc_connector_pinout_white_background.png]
    
    <p>Fig. 16. (left) IDC connector pinout of COMET and (right) 4-in-1 ESC JST connector pinout of our chosen ESC.</p>
</div>

Now, prepare the ESC cables for soldering. If you have never modified JST SH connectors before, this [tutorial video](https://www.youtube.com/watch?v=za-azgbZor8) may be helpful. For ESC #1, remove the cables for the fourth motor and the NC one (wires 6 and 7). For ESC #2, remove the cables for the battery (BAT+), ground (GND), the fourth motor (M4), and the NC one (wires 1, 2, 6, and 7). Battery and ground will be shared through the power connection.
<div align="center">
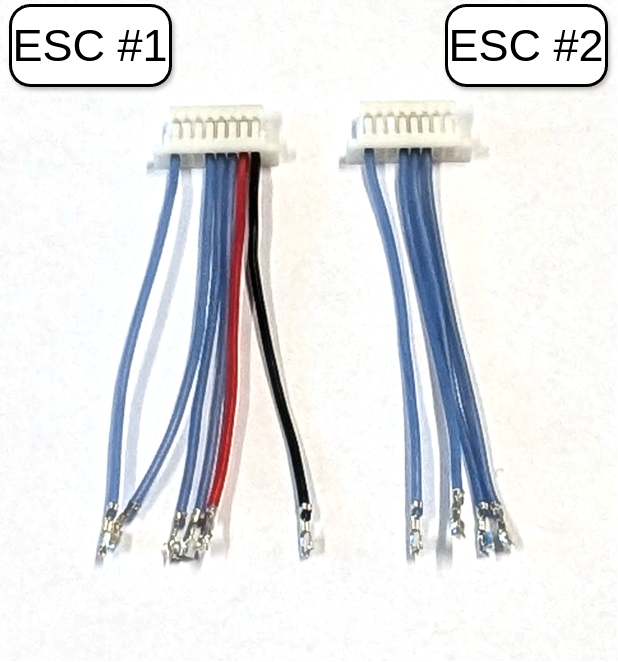
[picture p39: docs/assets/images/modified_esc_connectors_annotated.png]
    
    <p>Fig. 17. Modified connectors for ESC #1 and ESC #2.</p>
</div>

Take the two modified ESC connector cables and the ribbon cable (ES-09). First, cut the ESC connector cables to a length of approximately 3cm. Then, remove about 5mm of insulation from each cable end and apply solder. Place shrink tubes (approximately 10mm long each) over all of the wires of the ESC connectors to later prevent shorts. Solder the ESC connector wires to the ribbon cable wires according to Tab. 1. If you have access to a multimeter with conductivity measurement, check if all signals connect to the right pins.
<div align="center">
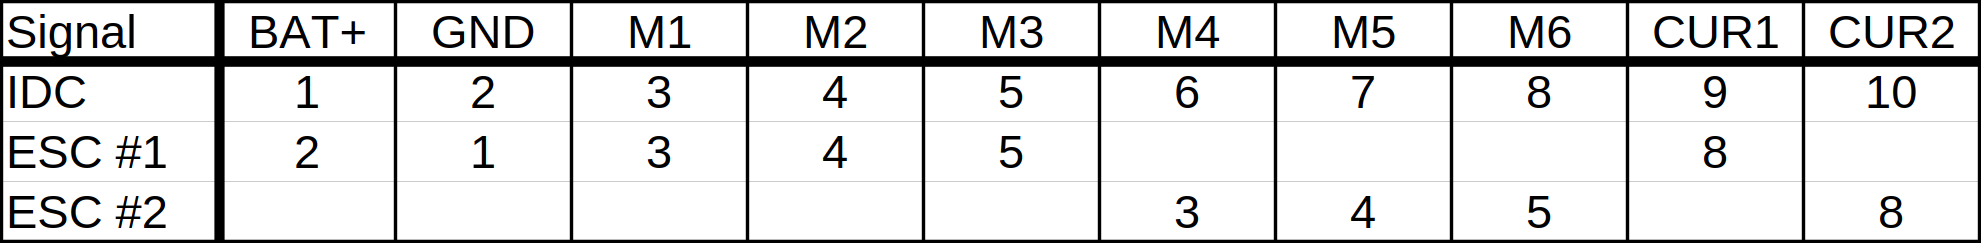
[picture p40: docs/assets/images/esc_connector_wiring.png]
    
    <p>Tab. 1. ESC connector wiring overview.</p>
</div>
<div align="center">
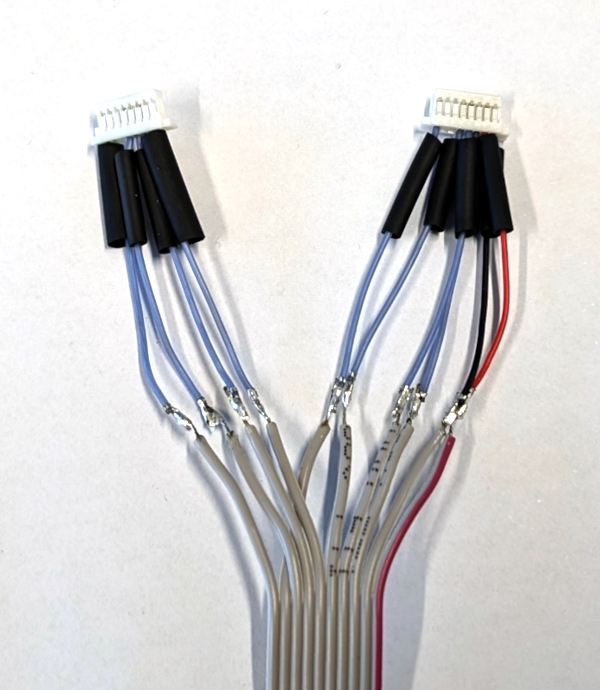
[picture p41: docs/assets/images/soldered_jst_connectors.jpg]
    
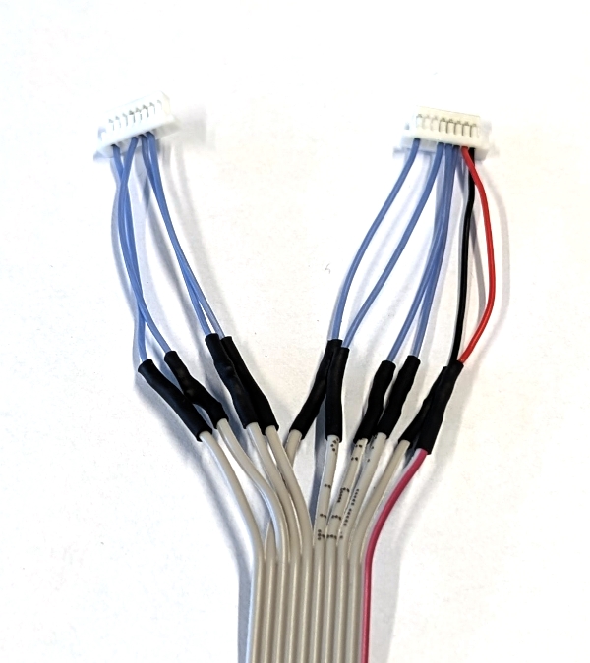
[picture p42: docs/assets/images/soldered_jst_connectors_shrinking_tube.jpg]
    
    <p>Fig. 18. (left) ESC connector wires soldered together; (right) shrink tubes insulating solder joints.</p>
</div>

Cut the resulting cable to a length of approximately 6 cm, measured from the front of the ESC connectors.
<div align="center">
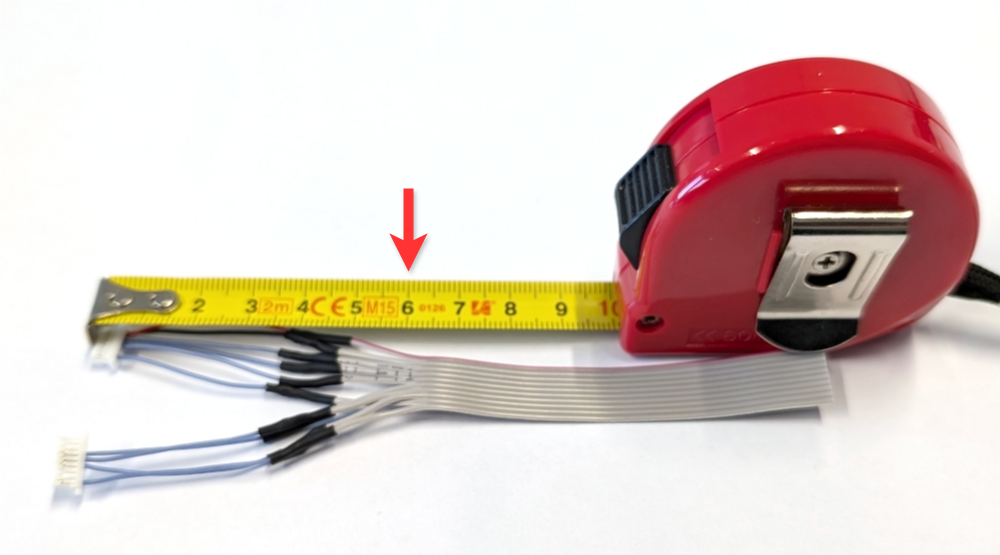
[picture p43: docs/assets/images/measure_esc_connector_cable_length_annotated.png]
    
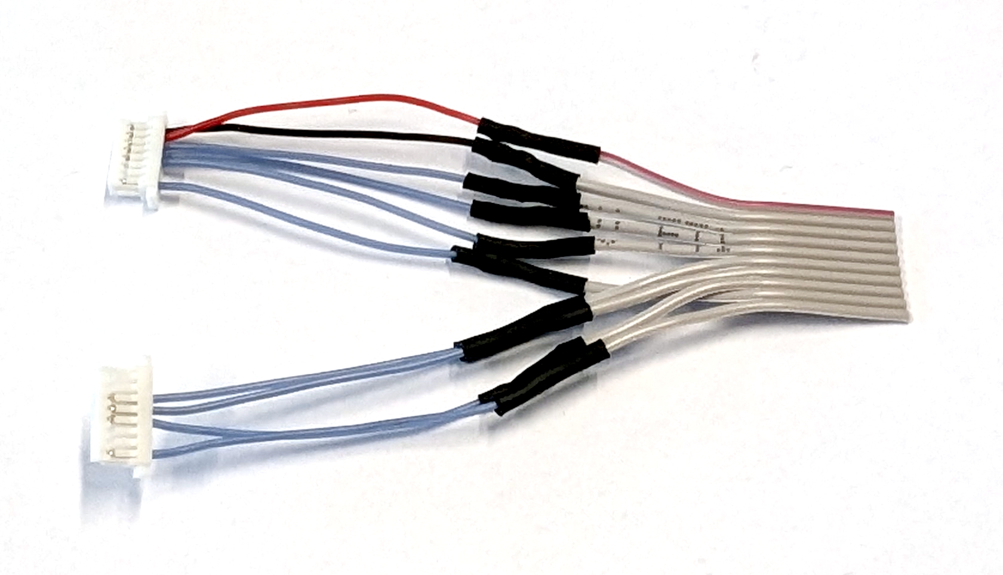
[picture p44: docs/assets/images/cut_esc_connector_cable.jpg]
    
    <p>Fig. 19. Cutting the connector cable to length (indicated by the red arrow).</p>
</div>

The final step is to insert the cut end of the ribbon cable into the IDC connector, aligning the red wire with the arrow on the connector. Then, close the IDC connector and pay attention to the click.
<div align="center">
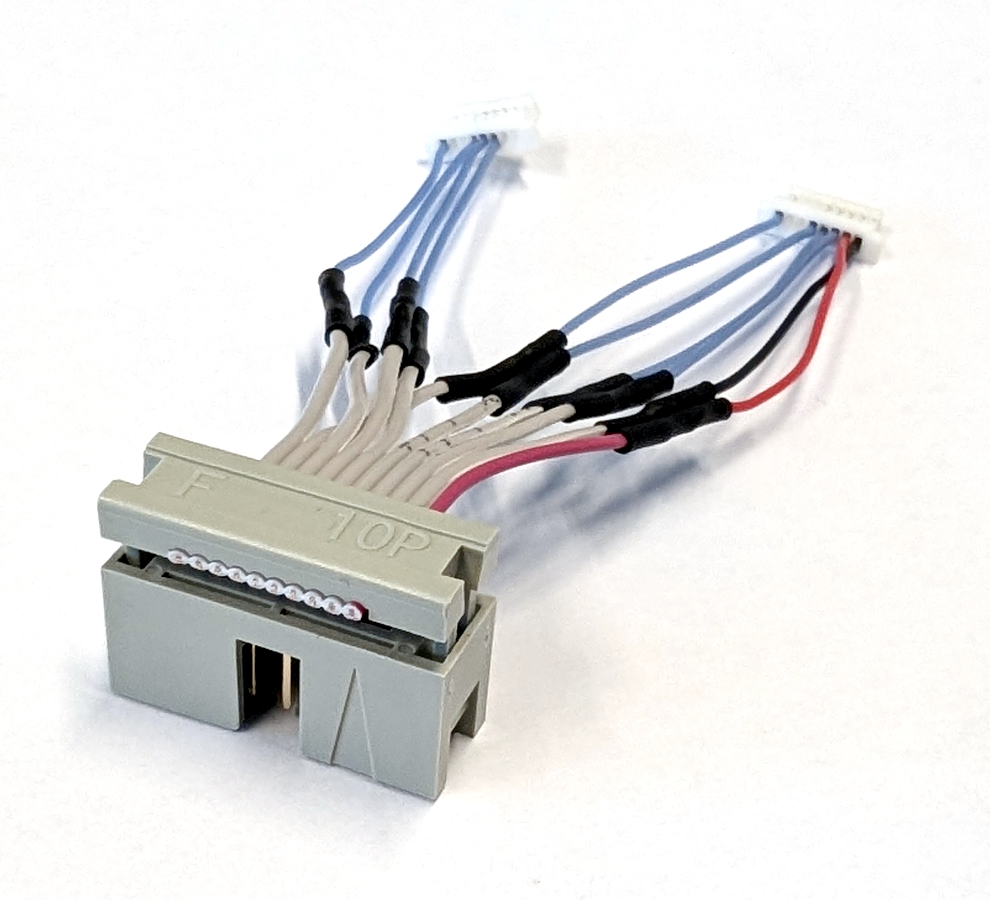
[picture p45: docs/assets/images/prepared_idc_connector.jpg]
    
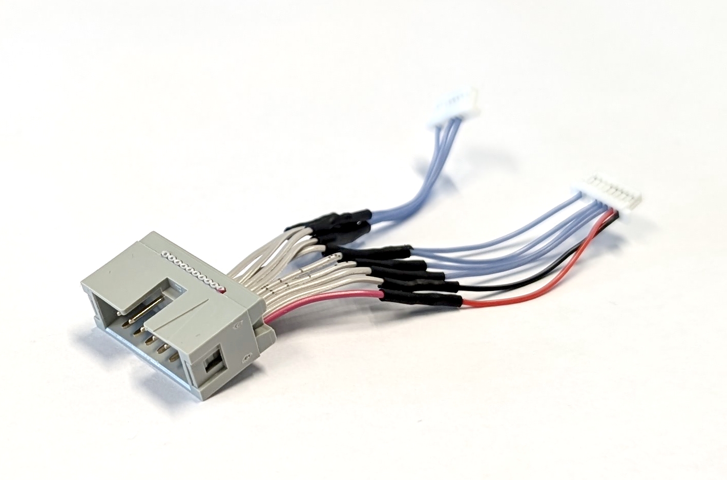
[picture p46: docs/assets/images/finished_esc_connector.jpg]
    
    <p>Fig. 20. (left) Alignment of the ribbon cable. (left) Fully assembled ESC connector cable.</p>
</div>

Do not connect the assembled ESC connector cable to the ESC yet. Store it for final assembly.

[Back to the top &#8593;](#table-of-contents)

#### Combining ESCs

Begin assembling the ESC stack by cutting the silicone cables (ES-07) into 18 equal pieces, each 15cm long. Save the remaining cables as spares. Remove approximately 3mm of insulation from one side of each cable and apply solder to the exposed copper wire. Then, solder the motor cable strands to the pads of motors 1, 2, and 3 for both ESC #1 and ESC #2. Each ESC should now have nine motor cables attached to it. To make the final assembly easier, label the motor connector cable on ESC #1 from M1 to M3, and label the motor connector cable on ESC #2 from M4 to M6.
<div align="center">
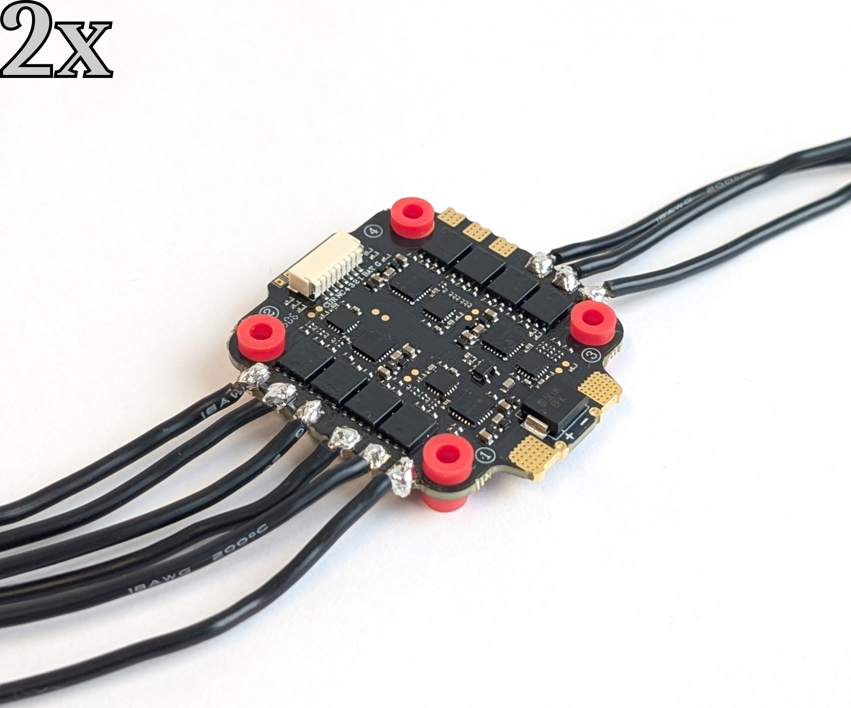
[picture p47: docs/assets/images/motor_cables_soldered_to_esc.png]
    
    <p>Fig. 21. Soldered motor cables to the pads of motors 1, 2, and 3 on one ESC.</p>
</div>

Use the M3 x 30mm (YF-11) screws from the later-assembled Y frame to properly align both ESCs and assemble the stack. Insert the screws through the rubber vibration dampers, ensuring that the JST connector side of each ESC faces down and the longer side of the dampers faces up. Secure the stack with the M3 self-locking nuts (ES-08). The top ESC is now referred to as #1, and the bottom one is referred to as #2.

Use a spare XT60 power cable to connect the positive and negative power pads of both ESCs. Strip 15 mm of insulation from the cable to expose the wire, then apply solder. Solder the wire to the pads to connect both ESCs, then trim any excess wire. Note that these power pads take time to heat up and require a great deal of power!
<div align="center">
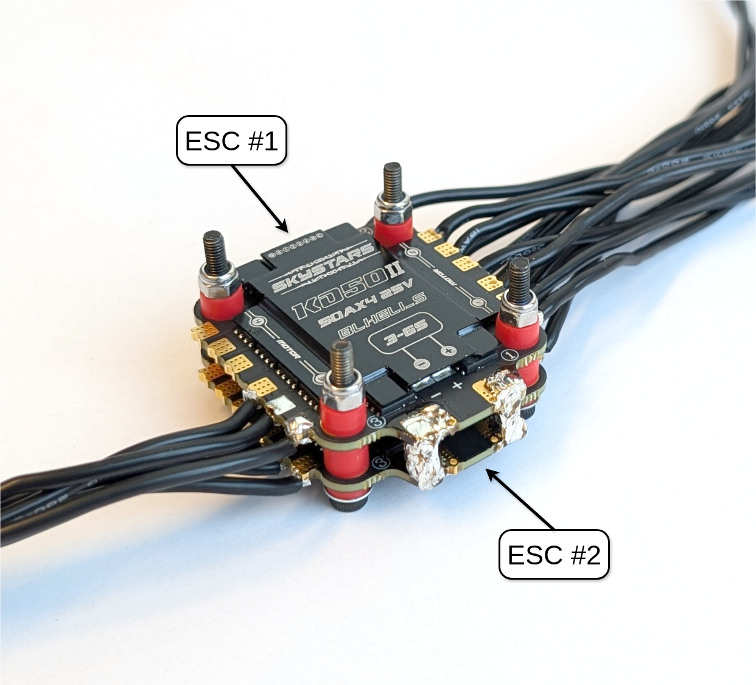
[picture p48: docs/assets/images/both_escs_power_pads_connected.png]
    
    <p>Fig. 22. The power pads are connected between ESC #1 and ESC #2.</p>
</div>

Next, attach the XT60 battery connector (ES-04) to the stack. First, remove 5 mm of insulation from the wires, then apply solder. Afterwards, solder the prepared XT60 battery connector perpendicular to the power wires between ESC #1 and ESC #2 as illustrated in Fig. 23.
<div align="center">
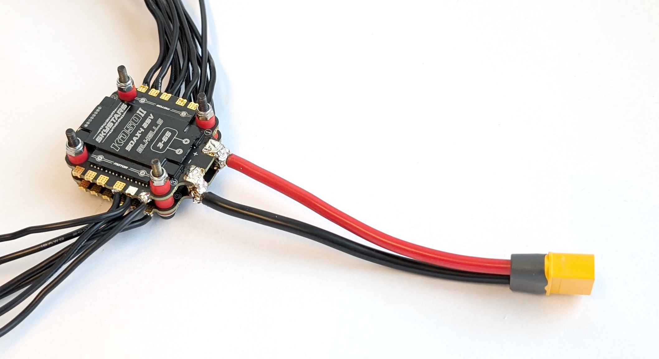
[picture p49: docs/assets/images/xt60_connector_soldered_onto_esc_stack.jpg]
    
    <p>Fig. 23. Connected XT60 battery connector to the ESC stack.</p>
</div>

Remove the M3 self-locking nuts from the stack, then place the capacitor holder (ES-01) on top of ESC #1, aligning its standoffs with the ESC. Check the polarity of the power pads on the ESC, then correctly insert the capacitor (ES-03) into the holder. Bend its legs so that they can be inserted into the associated through hole via. Refer to the ESC manual for the location of the capacitor's soldering point. Secure the capacitor in place with a zip tie, then solder it to ESC #1.  
<div align="center">
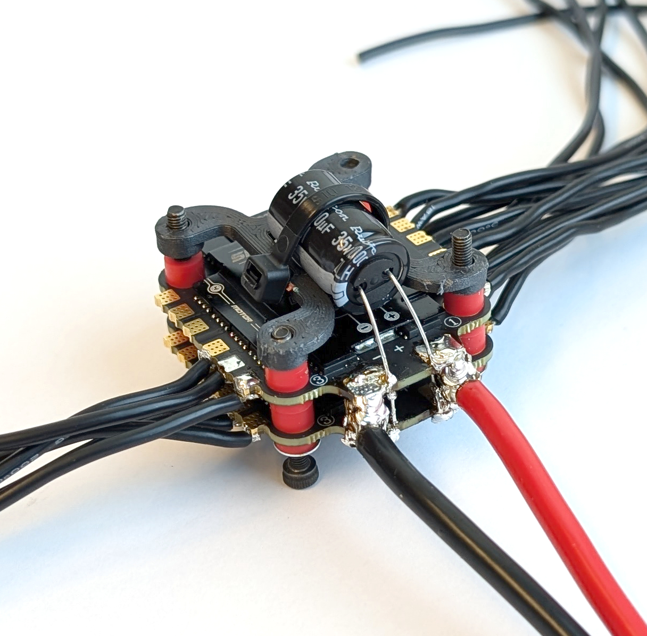
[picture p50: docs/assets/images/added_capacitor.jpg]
    
    <p>Fig. 24. The ESC stack with the added capacitor and its holder.</p>
</div>

<div align="center">
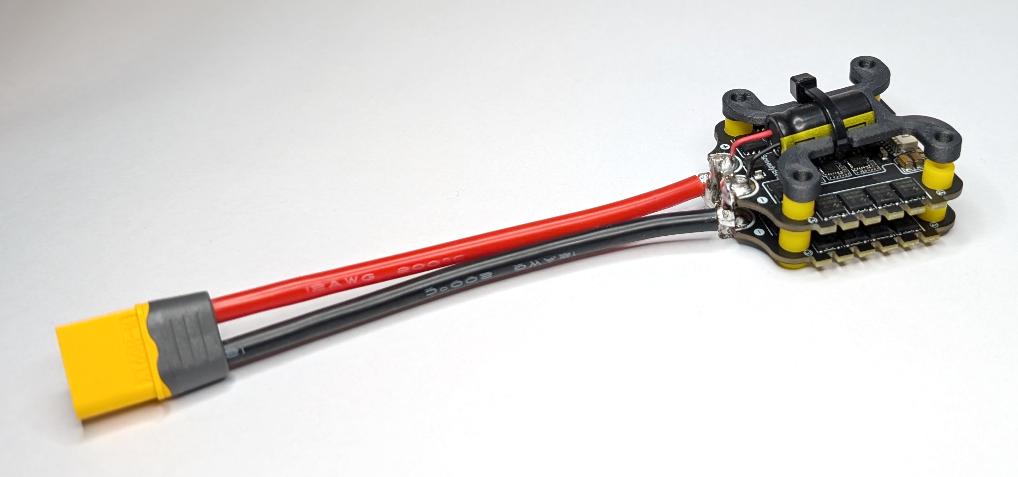
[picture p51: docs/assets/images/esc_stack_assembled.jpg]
    
    <p>Fig. 25. One fully assembled ESC stack.</p>
</div>

Store the M3 self-locking nuts (ES-08) for the final assembly.

[Back to the top &#8593;](#table-of-contents)

### Landing Gear

The landing gear is an important part of a drone because it ensures stability before take off. Three contact points are sufficient for stability, so this hexacopter with a Y configuration only needs three landing gear legs. Note that the rotor arms serve as legs, reducing the complexity and number of 3D-printed parts. All parts for this subgroup are labeled with the prefix "LG-*" in the [bill of materials](./bill_of_materials.ods). The following steps show how to assemble one landing gear.
<div align="center">
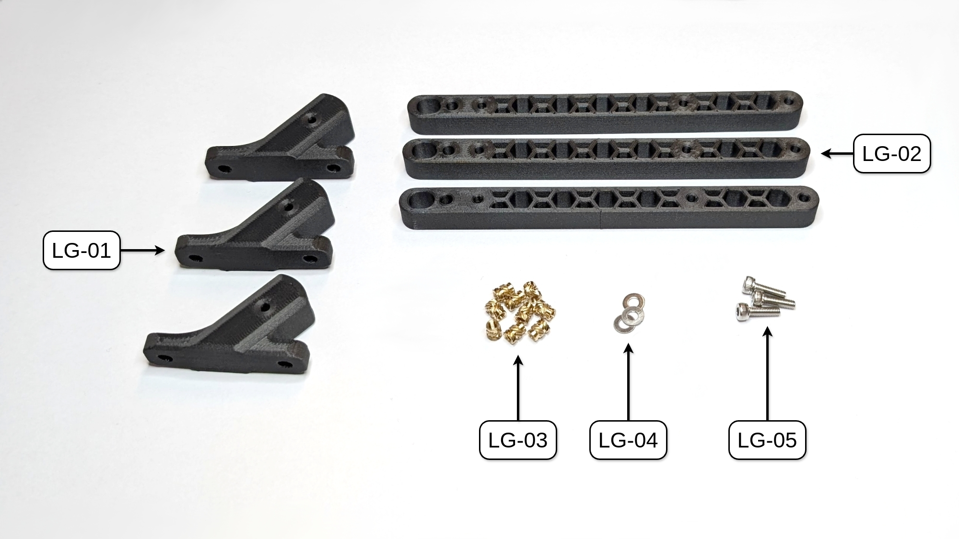
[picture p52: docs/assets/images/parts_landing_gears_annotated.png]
    
    <p>Fig. 26. All parts needed to build the three landing gears of COMET. <span style="color:red">NOTE: UPDATE IMAGE</span></p>
</div>

[Back to the top &#8593;](#table-of-contents)

#### Preparation of Parts

Thread inserts will be used throughout the build for easier assembly. These inserts are melted into the 3D-printed parts using a soldering iron with optional melting-aiding tips (see the tool list). If you have never worked with these type of threaded inserts before, this [tutorial video](https://www.youtube.com/watch?v=P7nHyI1TwKY) may be helpful. A note on the video: We achieved the best results with a temperature 15°C above the 3D printing temperature. For example, PC CF is printed at 290°C; therefore, the temperature should be set to 305°C. After setting the correct temperature, align the threaded inserts (LG-03) with the holes in the rotor arms (LG-02) and landing gear mounts (LG-01). 
<div align="center">
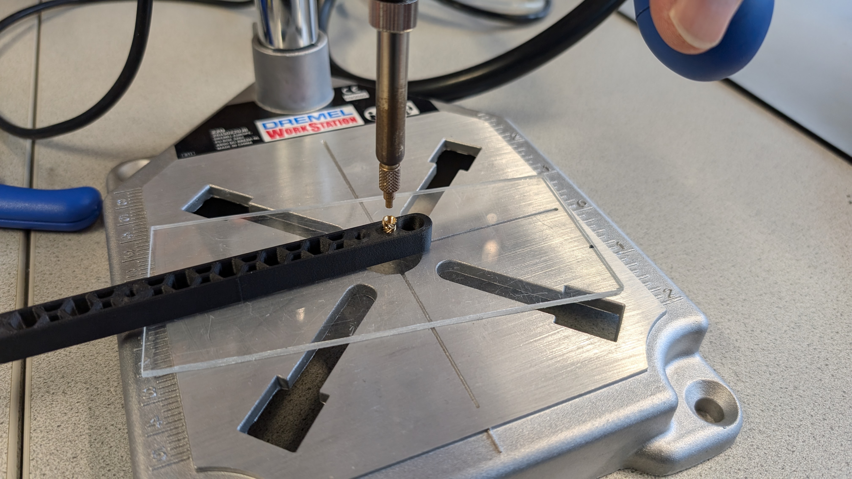
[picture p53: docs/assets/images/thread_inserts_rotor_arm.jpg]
    
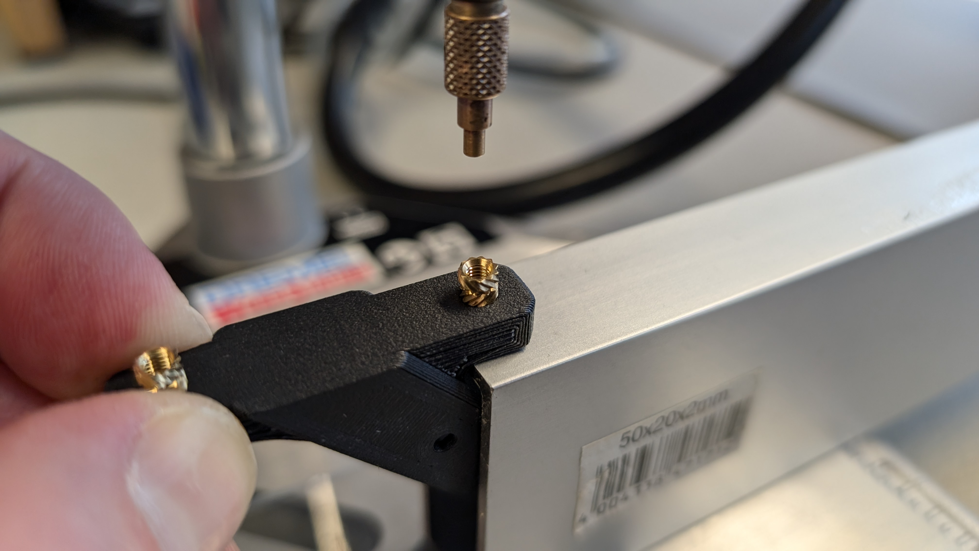
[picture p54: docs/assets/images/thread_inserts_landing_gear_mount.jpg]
    
    <p>Fig. 27. Examples of how to best align the thread inserts for the rotor arms (left) and landing gear mounts (right). <span style="color:red">NOTE: UPDATE RIGHT IMAGE</span></p>
</div>

Hold the soldering iron tip against the insert. Once the insert is heated up, push it into the part until it is flush with the surface. During this procedure, keep the soldering iron perpendicular to the surface to ensure the inserts are not at an angle. Note that the inserts and the surrounding plastic will get hot and need to cool down.
<div align="center">
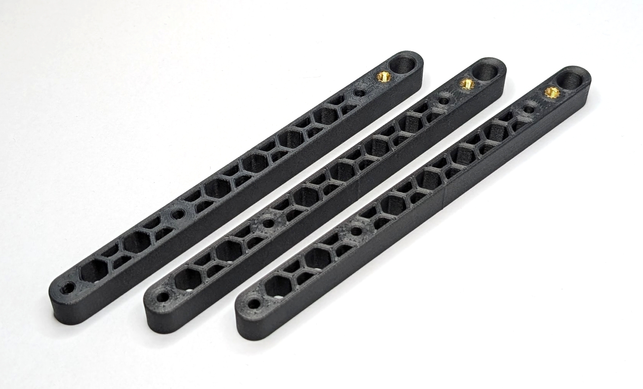
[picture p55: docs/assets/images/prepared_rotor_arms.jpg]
    
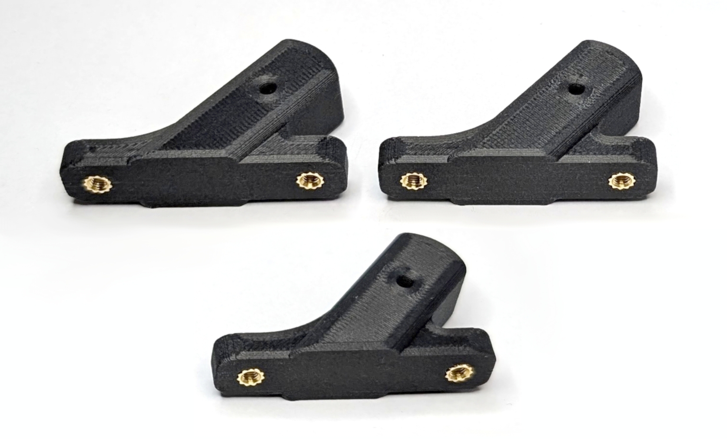
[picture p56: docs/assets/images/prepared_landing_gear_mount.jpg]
    
    <p>Fig. 28. Prepared rotor arms (left) and landing gear mounts (right). <span style="color:red">NOTE: UPDATE RIGHT IMAGE</span></p>
</div>

[Back to the top &#8593;](#table-of-contents)

#### Mechanical Assembly

Put the rotor arm (LG-02) into the landing gear mount (LG-01) and secure it with an M3 x 10mm screw and washer (LG-05 and LG-04). Repeat these steps three times to assemble all landing gears.
<div align="center">
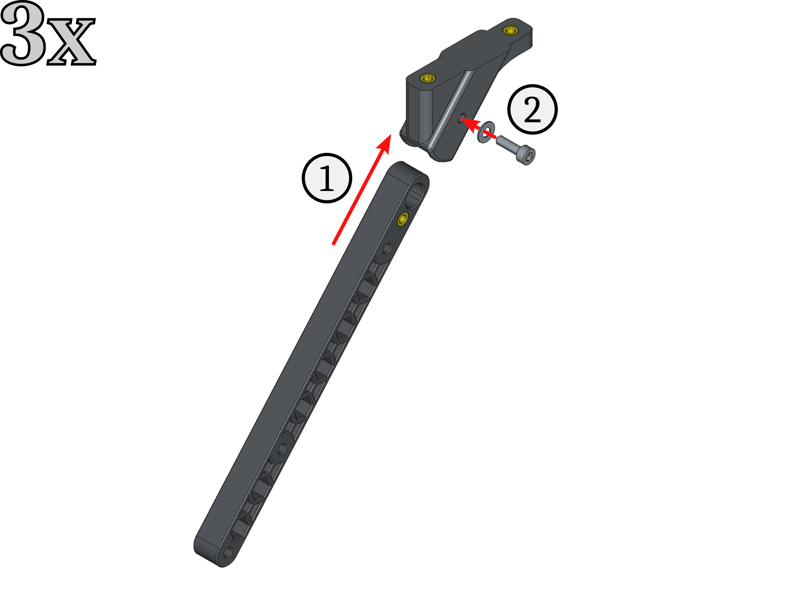
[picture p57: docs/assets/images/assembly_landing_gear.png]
    
    <p>Fig. 29. Assembly steps for one landing gear leg.</p>
</div>
<div align="center">
    
    <p>Fig. 30. All three assembled landing gear legs. <span style="color:red">NOTE: UPDATE IMAGE</span></p>
</div>

[Back to the top &#8593;](#table-of-contents)

### Battery Holder

This subgroup holds the battery that powers the entire drone. All parts for this subgroup are labeled with the prefix "BH-*" in the bill of materials. The following steps show how to assemble the battery holder.
<div align="center">
    
    <p>Fig. 31. All parts needed to assemble the battery holder of COMET.</p>
</div>

[Back to the top &#8593;](#table-of-contents)

#### Preparation of Parts

To prepare the battery holder (BH-01) for assembly, melt the two thread inserts (BH-02) into the holes to the left and right of the text "COMET." Again, ensure that the inserts are perpendicular to the surface and that the correct temperature is selected (e.g., PC CF at 305°C).
<div align="center">
    
    
    <p>Fig. 32. Preparation of the thread inserts (left) and finished preparation of the battery holder (right).</p>
</div>

[Back to the top &#8593;](#table-of-contents)

#### Mechanical Assembly

To assemble this subgroup, stick the silicone pad (BH-05) centered to the bottom of the battery holder. Then, thread the battery strap (BH-06) through the openings on the bottom of the battery holder (see Fig. 28 for reference).
<div align="center">
    
    
    <p>Fig. 33. Fully assembled battery holder (left) with inside view (right).</p>
</div>

Save the remaining M3 x 25mm screws (BH-03) and M3 washers (BH-04) for the final assembly.

[Back to the top &#8593;](#table-of-contents)

### RC Receiver

In order to control a drone with an RC remote through the flight control unit (FCU), one needs to add an RC receiver to it. All parts for this subgroup are labeled with the prefix "RC-*" in the [bill of materials](./bill_of_materials.ods). The following steps demonstrate how to assemble the rc receiver mount.
<div align="center">
    
    <p>Fig. 34. All parts needed to mount the RC receiver to COMET.</p>
</div>

[Back to the top &#8593;](#table-of-contents)

#### Connector Modification

To ensure the correct connection between the selected RC receiver (RC-02, [FlySky FS-A8S](https://www.flysky-cn.com/a8sspecifications?rq=FS-A8S)) and our chosen FCU (FC-01, [MicoAir H743 V2](https://micoair.com/flightcontroller_micoair743v2/), SBUS/CRSP port), it is necessary to modify the connector cable (RC-03). First, completely remove the green cable (one of the two outer cables) from both ends of the connector. Next, remove the yellow cable from one connector and insert it into the spot where the green cable was (connecting the SBUS/i-BUS signal to the FCU input). Attention: This step may differ depending on the FCU and RC receiver combination. Please refer to the respective user manuals for more information!
<div align="center">
    
    <p>Fig. 35. Modified RC connector cable: (left) FCU end; (right) RC end.</p>
</div>

[Back to the top &#8593;](#table-of-contents)

#### Preparation RC receiver

Apply a small cut piece of the double-sided tape (often include in the packkage), and ensure that the status LED of the receiver is not obstructed.
<div align="center">
    
    <p>Fig. 36. Double-sided tape applied to the RC receiver.</p>
</div>

[Back to the top &#8593;](#table-of-contents)

#### Mechanical Assembly

To assemble the RC receiver mount, first connect the cable (RC-03) to the RC receiver (RC-02). Then, remove the protection film from the double-sided tape. Thread the antenna of the RC receiver into the tube-like retainer of the mount (RC-01) and stick the receiver to the mount. Make sure the receiver's connector sits on the "ledge" to avoid it getting loose. Finally, secure the cable and receiver with zip ties.
<div align="center">
    
    <p>Fig. 37. Assembly steps of the RC receiver.</p>
</div>
<div align="center">
    
    <p>Fig. 38. Fully assembled RC receiver mount.</p>
</div>

[Back to the top &#8593;](#table-of-contents)

### Y Frame

The most important step in the build is assembling the drone's frame because all of its components work together to make the drone fly. The FCU and ESC stack are mounted and connected to the frame. The motors and propellers will also be attached to it. Lastly, the frame carries the power supply in the form of a battery. The Y frame design is different from the conventional hexacopters. It provides redundancy in propulsion and allows for the carrying of front-heavy payloads. All parts for this subgroup are labeled with the prefix "YF-*" in the [bill of materials](./bill_of_materials.ods). The following steps demonstrate how to assemble the drone's frame.
<div align="center">
    
    <p>Fig. 39. All parts needed to build the Y frame of COMET.</p>
</div>

[Back to the top &#8593;](#table-of-contents)

#### Preparation of Parts

As with the landing gear, begin by melting the thread inserts (YF-06) into the bottom mounting plate (YF-01, only one piece), the XT30 connector mount (YF-03), the ESC connector mount (YF-04), and the quick release base (YF-05). Ensure the thread inserts are perpendicular to the surface and the right temperature is selected (e.g., PC CF 305°C).
<div align="center">
    
    
    <p>Fig. 40. Example of how to best align the thread inserts for the bottom mounting plate (left). Prepared bottom mounting plate. All inserts should be flush with the bottom surface (right).</p>
</div>
<div align="center">
    
    
    <p>Fig. 41. Example of how to best align the thread inserts for the XT30 connector mount (left). The prepared XT30 connector mounts are mirrored (right). <span style="color:red">NOTE: UPDATE IMAGES</span></p>
</div>

The ESC connector mount (YF-04) and the quick release bases (YF-05) have thread inserts that face the mounting plates turned upside down. This ensures proper alignment of the components when they are mounted to the mounting plate. As illustrated in the figures, insert them into the holes upside down (with the smooth part of the insert facing up) and push them in until the knurl is in the component. The smooth surface should stick out.
<div align="center">
    
    
    <p>Fig. 42. Example of how to best align the thread inserts for the ESC connector mount (left). Prepared ESC connector mount (right).</p>
</div>
<div align="center">
    
    
    
    <p>Fig. 43. Example of how to align the thread inserts for the quick release base (left) correctly. Prepared quick release bases (middle) and a detailed look at the inverse thread inserts (right).</p>
</div>

[Back to the top &#8593;](#table-of-contents)

#### Assembly top Mounting Plate

Start by adding the XT30 connector to the top mounting plate, which is the one without the thread inserts. Then, insert the pre-wired XT30 cables (YF-07) into the prepared XT30 connector mounts (YF-03). Attach them to the mounting plate using the M3 x 10 mm screws (YF-09) and M3 washers (YF-08). Note that both XT30 mounts are mirrored.
<div align="center">
    
    <p>Fig. 44. Assembly steps for the XT30 connector mounts on the top mounting plate.</p>
</div>

To attach the quick release bases to the top mounting plate, align the protruding thread inserts with the mounting plate holes and push them in. Make sure the other thread inserts point outward. Then, secure them using the M3 x 25 mm screws (YF-10) and M3 washers (YF-08). The protruding threads of the screws allow the FCU to be mounted there.
<div align="center">
    
    <p>Fig. 45. Assembly steps for the quick release bases on the top mounting plate.</p>
</div>

Finally, insert the manufactured ESC connector cable from above into the cutout of the prepared ESC connector mount (YF-04). Secure it to the top mounting plate using M3 x 10 mm screws (YF-09) and M3 washers (YF-08). The cable goes to the back.
<div align="center">
    
    <p>Fig. 46. Assembly steps for the ESC connector mount on the top mounting plate.</p>
</div>

<div align="center">
    
    
    <p>Fig. 47. Fully assembled top mounting plate. <span style="color:red">NOTE: UPDATE IMAGES</span></p>
</div>

[Back to the top &#8593;](#table-of-contents)

#### Assembly bottom Mounting Plate

Next, take M3 x 30 mm screws (YF-11) and screw them into the thread inserts of the bottom mounting plate from the non-flush side.
<div align="center">
    
    <p>Fig. 48. Assembly steps for the ESC stack mount on the bottom mounting plate.</p>
</div>

<div align="center">
    
    <p>Fig. 49. Fully assembled bottom mounting plate. Note, the screws extend beyond the surface of the mounting plate.</p>
</div>

[Back to the top &#8593;](#table-of-contents)

#### Mechanical Assembly

The final step for this subgroup is to combine the mounting plates with the rotor arms (YF-02) to complete the Y frame of COMET. First, insert the remaining M3 x 25 mm screws with M3 washers through the rotor arm mounting holes in the top mounting plate, which holds the XT30 connectors, ESC connector, and quick release base. Then, attach the rotor arms to the top mounting plate using these M3 x 25mm screws. Finally, put the bottom mounting plate at the bottom of the stack. Thread the XT30 and ESC connector cables through the center hole of the bottom mounting plate toward the ESC stack that will soon be mounted.
<div align="center">
    
    <p>Fig. 50. Assembly steps for the rotor arms of the Y frame.</p>
</div>

<div align="center">
    
    <p>Fig. 51. Fully assembled Y frame of COMET. <span style="color:red">NOTE: UPDATE IMAGE</span></p>
</div>

[Back to the top &#8593;](#table-of-contents)

### Putting COMET together

Now that all the subgroups are complete, it's time to assemble the drone. The Y frame is the base of this operation, and one subgroup will be added to it at a time.

#### Adding the Landing Gear

Align each of the three landing gear legs with the protruding M3 x 25 mm screws of the Y frame, making sure they are facing away from the center. Then, mount the legs to the Y frame with the screws.
<div align="center">
    
    <p>Fig. 52. Assembly steps to attach the landing gear onto the Y frame.</p>
</div>

[Back to the top &#8593;](#table-of-contents)

#### Adding the Motor Blocks

Next, slide a motor block onto one rotor arm. Orient the motor so that the self-locking nuts point downward. This makes maintenance easier since all the nuts and screws are on one side. After that step, take one M3 x25mm screw (MB-06) with one M3 washer (MB-07) that were left over and put them through the last mounting hole. Secure the connection from below with another M3 washer (MB-07) and one M3 self-locking nut (MB-08). All of the steps are depicted in Fig. 48 and need to be repeated three times.
<div align="center">
    
    <p>Fig. 53. Assembly steps to attach the motor blocks onto the Y frame.</p>
</div>

Before moving on to the next subgroup, it is helpful to label the motor connector cables. Proper control of the drone requires the motors to be in the correct order with respect to their positions and spinning direction. We chose to use the iNAV flight software's motor ordering scheme, which is illustrated in Fig. 54.
<div align="center">
    
    
    <p>Fig. 54. The iNAV based motor order scheme <a href="https://github.com/iNavFlight/inav-configurator/blob/master/resources/motor_order/y6.svg">[source]</a> (left) and the correspondance to COMET (right).</p>
</div>

[Back to the top &#8593;](#table-of-contents)

#### Adding the ESC Stack

Turn the entire assembly upside down to more easily mount the ESC stack, route the motor cables, and solder the remaining MR30 connectors. Push the ESC connectors to the top and the XT30 connectors' cables to the the bottom right to easily connect them to the power pads on ESC #2  (see Fig. 56, top left). Put the ESC stack onto the four M3 x 30mm screws and secure it with the stored M3 self-locking nuts (ES-08). Be sure that the labels on the motor pads of motors #1 and #2 are facing left, as shown in Fig. 56. Ensure the capacitor holder is flush with the mounting plate and that no cables are pinched. Finally, connect the ESC connectors to ESC #1 and ESC #2, respectively.
<div align="center">
    
    <p>Fig. 55. Assembly steps to attach the ESC stack onto the Y frame.</p>
</div>

<div align="center">
    
    <p>Fig. 56. Result of the finished assembly step.</p>
</div>

Next, add the female MR30 connectors (ES-06) to the motor cables. First, route the motor cables according to the labels on the motor blocks. Fig. 57 and 58 illustrate the best way to do this. The motor cables for motors M1 and M4 run left (M4) and right (M1) of the landing gear leg on the back. Use a zip tie as shown in Fig. 57 to hold them in place, but do not tighten it yet to allow for movement of the cables. Do this for the remaining M2, M3, M5, and M6 cables according to Fig. 58 too.
<div align="center">
    
    <p>Fig. 57. This is an example of how to route motor cables M1 and M4 with a ziptie.</p>
</div>
<div align="center">
    
    
    <p>Fig. 58. This is an example of cable routing of the motor cables M3 and M6 fixed with a zip tie. It shows the front-side view (left) and back-side view (right). The routing is mirrored for M2 and M5 on the other rotor arm.</p>
</div>

To solder the MR30 female connector to one motor cable bundle (M1 - M6), first cut the bundle to length by holding it against the front end of the male MR30 connector on the respective BLDC motor. Cut the cables and strip about 3 mm of insulation from each wire. Apply solder to the exposed wires and the connector’s solder cups. Slide the three motor wires through the MR30 female connector’s solder cover (the gray piece), then solder the wires to the cups (connector receptacle). Make sure there are no shorts between wires or pins, and check the joint by gently pulling on the connector while holding the cable. Push the solder cover onto the connector until it clicks into place, then connect the male and female MR30 connectors. Repeat for the remaining five connectors.
<div align="center">
    
    
    
    <p>Fig. 59. The process of soldering the female MR30 connector onto the motor cables from the ESCs: (left) Cut the cable to the desired length using the BLDC motor's MR30 connector as a reference; (middle) solder the wire and connector together; and (right) the finished connector. <span style="color:red">NOTE: TAKE IMAGES</span></p>
</div>

Finish by soldering both XT30 connector cables to the positive (red) and negative (black) power pads of ESC #2. If you have a multimeter that measures conductivity, check that the XT60 and both XT30 connectors have the same polarity.
<div align="center">
    
    <p>Fig. 60. XT30 connector cables soldered to ESC #2. <span style="color:red">NOTE: UPDATE IMAGE</span></p>
</div>

To complete this step, secure the motor connector cables to each rotor arm with a zip tie around the middle of the arm. Tighten all other zip ties used in this subgroup. This will prevent the cables from getting caught in the rotors and causing the drone to crash.
<div align="center">
    
    <p>Fig. 61. Zip tie applied to the middle of the rotor arm. <span style="color:red">NOTE: UPDATE IMAGE</span></p>
</div>

[Back to the top &#8593;](#table-of-contents)

#### Adding the Battery Holder

Place the prepared battery holder over the wired ESC stack and attach it to the bottom mounting plate using the remaining M3 x 25mm screws (BH-03) and M3 washers (BH-04). Ensure that the XT60 cable and any other cables are not pinched or damaged in the process.
<div align="center">
    
    <p>Fig. 62. Assembly steps attach the battery holder onto the Y frame.</p>
</div>

[Back to the top &#8593;](#table-of-contents)

#### Adding the RC receiver

First, remove the two M3 x 25mm screws and M3 washers securing the landing gear leg next to the XT60 power connector. Place the prepared RC receiver mount on top of the mounting plate, aligning the mounting holes. Finally, secure the RC receiver mount and the landing gear leg to the Y frame using the M3 x 25mm screws and M3 washers again.
<div align="center">
    
    <p>Fig. 63. Assembly step attach the RC receiver onto the Y frame</p>
</div>

[Back to the top &#8593;](#table-of-contents)

#### Adding the Handle

To attach the handle (CC-01) to the Y frame, slide it down from above onto the top mounting plate, aligning its mounting holes with the threaded inserts of the XT60 mounts (YF-03). Make sure the top pointer of the handle is aligned with the mounting holes on the top mounting plate, as seen in Fig. 63. Finally, secure the handle with the remaining two M3 x 10mm screws and M3 washers (YF-09 and YF-08).
<div align="center">
    
    
    <p>Fig. 64. Assembly step to attach the carry handle onto the Y frame (left) and detailed look at the handle alignment (right).</p>
</div>

[Back to the top &#8593;](#table-of-contents)

### Final Checks

- The motor wires are strain-relieved and kept clear of the propellers.
- There is no wobble, and the parts are secured firmly.
- All power connections have correct polarity.
- There are no exposed strands, and the joints are shiny and mechanically sound.
- The FC is isolated via soft mounts.
- The battery strap is tight, and the pad prevents slippage.
- The center of gravity is acceptable with minimal pitch bias.

[Back to the top &#8593;](#table-of-contents)

## Finished Build

Congratulations! You successfully built COMET! Great job! 😃
<div align="center">
    
    
    <p>Fig. 65. A fully assembled COMET in a FreeCAD (left) and in reality (right). <span style="color:red">NOTE: UPDATE RIGHT IMAGE</span></p>
</div>

[Back to the top &#8593;](#table-of-contents)

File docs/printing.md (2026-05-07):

<!-- SPDX-License-Identifier: CC-BY-SA-4.0 -->

# 3D-Print Guide - NOTES

### 3) 3D print the frame

Use 3MF projects in hardware/mechanical/exports/3mf/ or follow manifest.csv.
STL/STEP are in hardware/mechanical/exports/{stl,step}/.
Follow docs/printing.md for materials, orientation, and post‑processing.

0) ensure that 3D printer calibration for elephant foot and over-/under-extrusion is done!
- See the section [Printed Parts](#printed-parts) for material and settings.
- Follow instructions
- STL and 3MF files are in hardware/exports/ and hardware/prints/3mf/.
- See mechanical/prints/README.md for recommended materials, orientations, and slicer profiles.
- Download STL/STEP: mechanical/exports/{stl,step}/
- Optional: use provided 3MF projects for a known-good profile.

- Verify printed parts match dimensions (critical hole diameters, arm thickness).

Printed parts
- See ../../hardware/mechanical/exports/stl/ and manifest.csv for settings
- Recommended materials: PC/CF (frame), and PETG (color-coding parts)
1) Print parts according to manifest and 3MF projects.
2) Install heat-set inserts (where specified).

## 3D printing guidance

- Use the 3MF projects to capture intended orientation, supports, and modifiers.
- Typical settings (starting point; see manifest.csv for part-specific):
  - Nozzle: 0.4 mm; Layer: 0.20 mm
  - Walls: 4; Top/Bottom: 6; Infill: 35-50% (gyroid) for arms
  - Material: PC/CF-Nylon
- Tolerances (rule of thumb):
  - Write values in params/default.yaml
- Test coupons: test/coupons/ includes hole ladders and insert gauges.

## Printed Parts

- Recommended materials:
  - PC-CF or ABS for the drone's frame (separte 3mf project file)
  - PETG for color-coding/cosmetic parts (separte 3mf project file)
- Baseline settings (see part notes and screenshots in docs/printing/):
  - Nozzle: 0.4 mm
  - Layer height: 0.2 mm (first layer 0.3mm)
  - Perimeters: 4
  - Top Solid layers: 6
  - Bottom Solid layers: 6
  - Infill: 20% Gyroid
  - Orientation: each STL is oriented “as printed”
- Slicer profiles:  
  Provided 3MF projects for [PrusaSlicer](https://github.com/prusa3d/prusaslicer) in hardware/prints/3mf/ with per‑category settings.
- Heat‑set inserts: sizes and temperatures in part notes (docs/printing/) - README.md
- Post‑processing in hardware/prints/README.md (threaded inserts); post‑processing (reaming, tapping, heat‑set insert temperatures); removal of support.

- Files:
  - Editable: hardware/freecad/parts/*.FCStd
  - Interchange: hardware/exports/step/*.step
  - Mesh: hardware/exports/stl/*.stl
  - Slicer projects: hardware/prints/3mf/

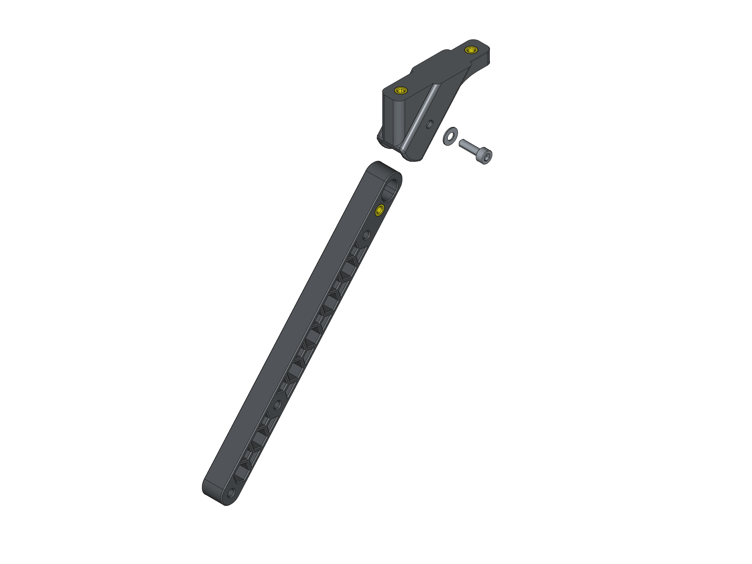
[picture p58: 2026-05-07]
docs/assets/images/landing_gear_assembly_exploded_view.png

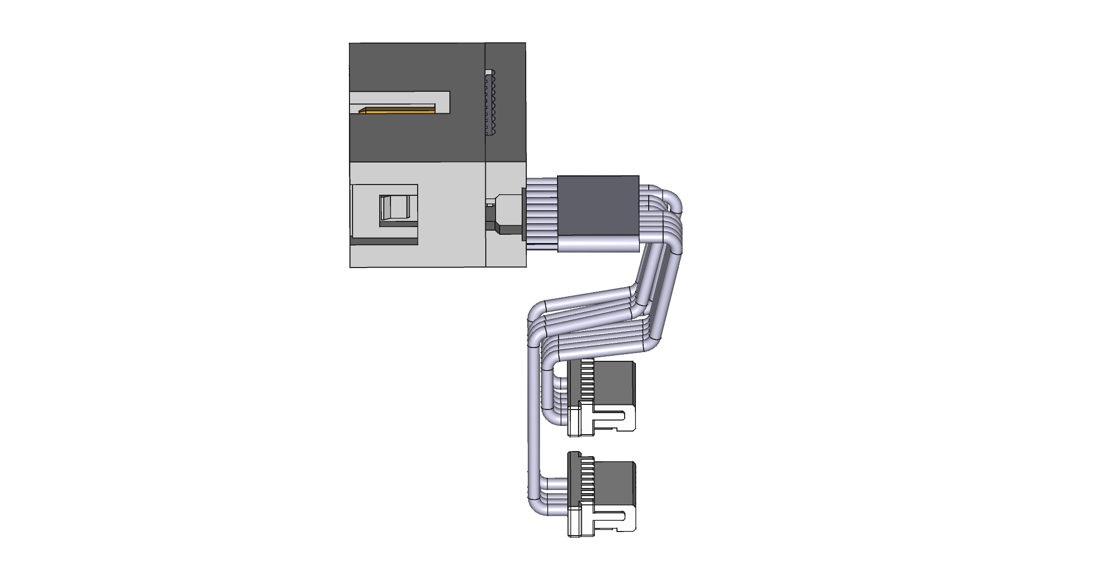
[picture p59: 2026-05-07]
docs/assets/images/assembly_esc_connector_cable.png

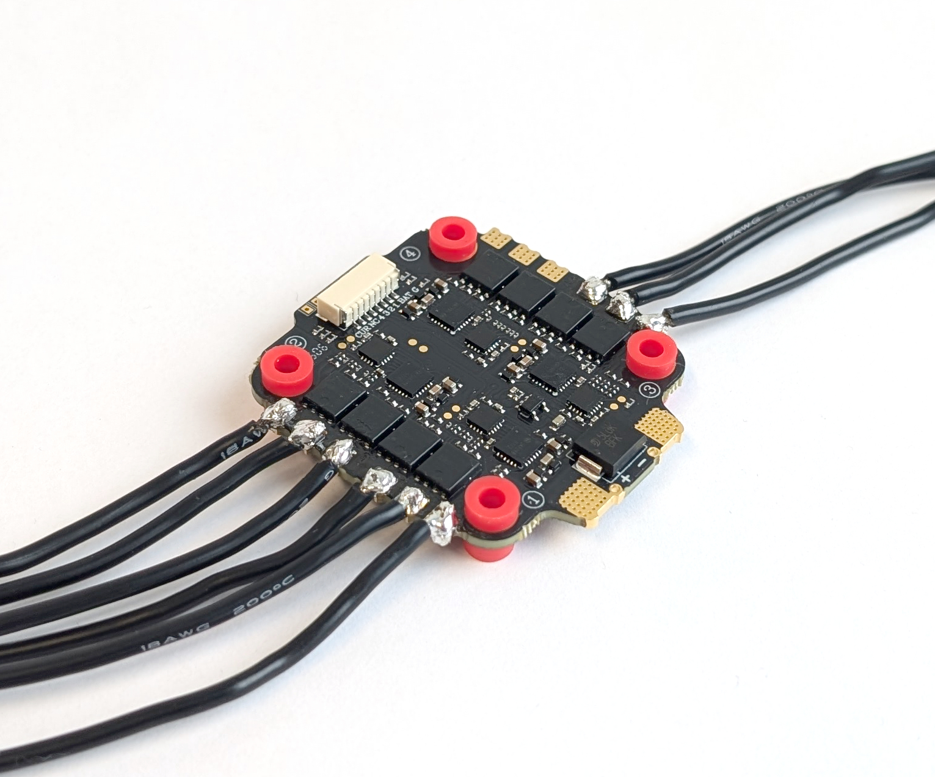
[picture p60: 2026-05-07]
docs/assets/images/motor_cables_soldered_to_esc.jpg

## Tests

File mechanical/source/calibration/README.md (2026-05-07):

Add a README.md in that folder explaining each test, the parameters they depend on (e.g., HoleClearance, InsertOD), and how to interpret results.

With this parameter set, you can switch materials, printers, or variants by editing one params file, then run your headless script to recompute and re‑export all parts automatically.

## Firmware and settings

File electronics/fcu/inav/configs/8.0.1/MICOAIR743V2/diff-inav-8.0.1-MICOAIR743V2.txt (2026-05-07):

# SPDX-License-Identifier: CC0-1.0
# Copyright (c) 2026 Christoph Böhm
# 
# This configuration is dedicated to the public domain under CC0-1.0.
# You may copy, modify, and use it for any purpose without permission.
# 
# version
# INAV/MICOAIR743V2 8.0.1 Mar 28 2025 / 09:59:40 (ae47bcba) 
# GCC-13.2.1 20231009

# start the command batch
batch start

# resources

# Timer overrides
timer_output_mode 0 MOTORS
timer_output_mode 2 MOTORS
timer_output_mode 3 MOTORS
timer_output_mode 11 MOTORS

# Outputs [servo]

# safehome

# Fixed Wing Approach

# geozone

# geozone vertices

# features
feature BLACKBOX
feature PWM_OUTPUT_ENABLE

# beeper

# blackbox
blackbox -NAV_ACC
blackbox -NAV_POS
blackbox -NAV_PID
blackbox -MAG
blackbox -ACC
blackbox -ATTI
blackbox -RC_DATA
blackbox -RC_COMMAND
blackbox MOTORS
blackbox GYRO_RAW
blackbox PEAKS_R
blackbox PEAKS_P
blackbox PEAKS_Y
blackbox -SERVOS

# Receiver: Channel map

# Ports

# LEDs

# LED color

# LED mode_color

# Modes [aux]
aux 0 0 0 1800 2100
aux 1 1 1 900 2100

# Adjustments [adjrange]

# Receiver rxrange

# temp_sensor

# Mission Control Waypoints [wp]
#wp 0 invalid

# OSD [osd_layout]

# Programming: logic

# Programming: global variables

# Programming: PID controllers

# OSD: custom elements

# master
set gyro_main_lpf_hz = 110
set gyro_dyn_lpf_min_hz = 85
set gyro_dyn_lpf_max_hz = 300
set gyro_dyn_lpf_curve_expo = 3
set dynamic_gyro_notch_q = 250
set dynamic_gyro_notch_min_hz = 73
set dynamic_gyro_notch_mode = 3D
set setpoint_kalman_q = 200
set gyro_zero_y = 3
set ins_gravity_cmss =  977.579
set acc_hardware = BMI088
set acczero_x = -9
set acczero_y = -10
set acczero_z = 4
set accgain_x = 4081
set accgain_y = 4097
set accgain_z = 4083
set mag_hardware = QMC5883
set magzero_x = -1418
set magzero_y = 496
set magzero_z = 774
set maggain_x = 788
set maggain_y = 906
set maggain_z = 938
set baro_hardware = SPL06
set serialrx_provider = IBUS
set blackbox_rate_denom = 2
set motor_pwm_protocol = DSHOT600
set failsafe_procedure = DROP
set applied_defaults = 2
set airmode_type = THROTTLE_THRESHOLD
set inav_w_z_baro_p =  0.350
set debug_mode = DYN_GYRO_LPF

# control_profile
control_profile 1

set mc_i_pitch = 90
set mc_d_pitch = 27
set mc_cd_pitch = 88
set mc_p_roll = 36
set mc_i_roll = 82
set mc_d_roll = 24
set mc_cd_roll = 80
set mc_p_yaw = 43
set mc_i_yaw = 84
set mc_cd_yaw = 90
set dterm_lpf_hz = 105
set d_boost_min =  1.000
set d_boost_max =  1.000
set antigravity_gain =  2.000
set antigravity_accelerator =  5.000
set smith_predictor_delay =  1.447
set tpa_rate = 20
set tpa_breakpoint = 1200
set rc_expo = 80
set rc_yaw_expo = 80
set roll_rate = 70
set pitch_rate = 70
set yaw_rate = 60
set ez_enabled = ON
set ez_response = 92
set ez_damping = 108
set ez_stability = 110
set ez_aggressiveness = 80
set ez_rate = 134
set ez_expo = 118

# mixer_profile
mixer_profile 1

set model_preview_type = 6
set motorstop_on_low = OFF

# Mixer: motor mixer

mmix reset

mmix 0  1.000  0.000  1.333  1.000
mmix 1  1.000 -1.000 -0.667 -1.000
mmix 2  1.000  1.000 -0.667 -1.000
mmix 3  1.000  0.000  1.333 -1.000
mmix 4  1.000 -1.000 -0.667  1.000
mmix 5  1.000  1.000 -0.667  1.000

# Mixer: servo mixer

# battery_profile
battery_profile 1


# save configuration
save

# end the command batch
batch end

# 

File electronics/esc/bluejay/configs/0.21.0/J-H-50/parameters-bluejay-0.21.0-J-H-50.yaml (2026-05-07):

# SPDX-License-Identifier: CC0-1.0
# Copyright (c) 2026 Christoph Böhm
# 
# This configuration is dedicated to the public domain under CC0-1.0.
# You may copy, modify, and use it for any purpose without permission.
# 
# Settings for Bluejay v0.21.0 on J-H-50
bluejay_version: 0.21.0
target: J-H-50
esc_layout: 4in1 (2x)                 # or "single"

defaults:
  pwm_khz: 48
  min_startup_pwr: 1000
  max_startup_pwr: 1020
  motor_timing: 22.5° (MediumHigh)
  demag: Low
  rpm_rampup: 9x
  beacon:
    beep_strength: 20
    beacon_strenth: 80
    beacon_delay: 10 minutes
  safety:
    esc_rating: 2S+
    temp_protection: 140 C
    force_edt: Off                    # On/Off
  brake:
    brake_on_stop: Off                # On/Off
    max_breaking: 255

motors:
# If this is not done in hardware, reverse the motor spin direction here.
  m1:
    direction: Normal                 # Normal/Reverse
    led: Off                          # On/Off
  m2:
    direction: Normal                 # Normal/Reverse
    led: Off                          # On/Off
  m3:
    direction: Normal                 # Normal/Reverse
    led: Off                          # On/Off
  m4:
    direction: Normal                 # Normal/Reverse
    led: Off                          # On/Off
  m5:
    direction: Normal                 # Normal/Reverse
    led: Off                          # On/Off
  m6:
    direction: Normal                 # Normal/Reverse
    led: Off                          # On/Off

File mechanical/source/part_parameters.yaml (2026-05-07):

# SPDX-License-Identifier: CC0-1.0

# General part settings
elephant_foot_chamfer: 0.4 mm # Chamfer the edges of the part to avoid the "elephant footing" of 3D prints. Compensating for the typical expansion of the first layers.

###############################################
# [1] Pre clearance gauge test values         #
###############################################
# Set heat-set threaded insert outer and knurl diameter
# Values based on: https://www.ruthex.de/en/products/ruthex-gewindeeinsatz-m3-100-stuck-rx-m3x5-7-messing-gewindebuchsen
threaded_insert_outer_diameter:    3.9 mm # Outer diameter of the threaded insert. This value should be below 5mm.
threaded_insert_knurl_diameter:    4.6 mm # Diameter of the knurled section of the threaded insert. This value should be below 7mm.
# Set the minimal wall thickness for chosen heat-set threaded insert
threaded_insert_minimum_thickness: 1.6 mm # Additional material around the threaded insert (boss). This value is often below 2mm.
# The minimal outer diameter of the threaded insert wall: threaded_insert_minimal_boss_diameter = threaded_insert_outer_diameter + threaded_insert_clearance + 2*threaded_insert_minimum_thickness

###############################################
# [2] Values based on clearance gauge results #
###############################################
# Heat-set threaded insert hole clearence
threaded_insert_clearance:         0.2 mm # The amount added to the nominal diameter.
# M3 screw through hole clearance
m3_hole_diameter_clearance:        0.2 mm # The amount added to the nominal diameter.
# M2 screw through hole clearance
m2_hole_diameter_clearance:        0.2 mm # The amount added to the nominal diameter.
# Fit of rotor arm mountings
rotor_arm_mounting_clearence:      0.2 mm # The amount added to the nominal dimension.
